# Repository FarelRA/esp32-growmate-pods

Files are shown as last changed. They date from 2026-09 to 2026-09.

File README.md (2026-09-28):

# GrowMate Pods (ESP32-CAM, indoor)

Indoor plant pod: an ESP32-CAM with OV2640 camera monitors a single
plant pot plus its water tank and drives two actuators — a 5 V micro
pump and a full-spectrum LED strip. Six sensing channels (tank level,
light, soil moisture, humidity, temperature, camera) and two command
channels (pump timed in ms, latched grow light). Sense → POST → the
server commands pump / light (never both at once — server-paced
interlock) and serves JPEG stills.

Status: pre-alpha. Device↔server contract is frozen at v1; hardware
is carrier rev A. The matching outdoor unit lives in
`rpi-growmate-tech` (same v1 contract, different iron).

## Features

- Raw-only telemetry (ADC codes + native DHT) with server-side
  calibration; camera JPEG upload on a 15-minute period.
- Timed pump doses (30 s cap, dry-tank interlock) and latched grow
  light (24 h failsafe auto-off), both server-commanded.
- HTTPS OTA with semver gating; MAC-birth identity + server claim flow.
- Full KiCad hierarchy, BOM, and release PDFs in [`schematic/`](schematic/)
  ([pods.pdf](schematic/mfg/pods.pdf)); net-by-net text reference in
  [`docs/04-wiring.md`](docs/04-wiring.md).

## Requirements

- Hardware: AI-Thinker ESP32-CAM module, carrier PCB (see schematic),
  5 V micro pump, 20 cm LED strip, probes, DHT22, BLP673 LiPo pack.
- Host: Python 3 + [PlatformIO](https://platformio.org/) (`pip install
  platformio`), plus a USB-UART adapter for flashing (the module has
  no auto-reset circuit).
- Optional for schematics: KiCad 10 CLI + Inkscape (see
  [`tools/sch_plot.sh`](tools/sch_plot.sh)).

## Installation

```bash
pip install platformio
pio run                    # build .pio/build/growmate-pods/firmware.bin
```

## Usage

Flash (hold BOOT at power-on for download mode, release + reset after):

```bash
pio run --target upload    # uses tools/flash.sh: no_reset/no-stub, 115200
pio device monitor         # or: tools/monitor.sh
```

Onboard: join AP `GrowMate-<last6 of device ID>` with password
`GrowMate-<last6 of WiFi MAC>` from the manufacturing claim sheet
(never the boot log) → `http://192.168.4.1` → home WiFi. Then
calibrate each probe (raw ends stored server-side). Full procedure:
[`docs/07-operations.md`](docs/07-operations.md).

## Tests

```bash
tools/test_all.sh          # Unity suite (PlatformIO native, no hardware)
                           # + host contract checks
```

116 Unity tests, ~98% line coverage of firmware logic
(`pio test -e native` for detail). If the suite and the device ever
disagree, the device wins — then fix the test the same day.

## Docs

`00-overview`, `01-pinout`, `02-power`, `03-sensors-actuators`,
`04-wiring`, `05-firmware`, `06-api`, `07-operations`,
`08-server-changes` — in [`docs/`](docs/). Start at
[`docs/00-overview.md`](docs/00-overview.md); bring-up order lives in
`04-wiring.md`; the server team's contract is `06-api.md` +
`08-server-changes.md`.

## Roadmap

- First field units on rev A carriers (soak + calibration validation).
- Server backend completing the `08-server-changes` contract
  (calibration store, XOR pacing, OTA hosting).
- Rev 2 notes collected in issues: real power-path charger
  (MCP73871 or load-share), probe ESD/TVS.

## Contributing

Private pre-alpha: coordinate before large changes. Rules that keep
the project consistent:

- Tests must stay green (`tools/test_all.sh`); new behavior needs tests.
- Docs change with code — pinout, wiring, power, and API docs are
  normative, not commentary.
- SKiDL (`schematic/pods.py`) is the hardware source of truth; the
  placed sheets follow it via `tools/sch_gate.sh`, never hand edits.

## License

GPLv3 — see LICENSE.

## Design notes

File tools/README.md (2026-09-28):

# Pods tools (run from the repo root)

Device workflow (ESP32-CAM has no auto-reset; never assert DTR/RTS):
- `flash.sh PORT BAUD BUILD_DIR PACKAGES_DIR` — manual flash (also used
  by PlatformIO `upload_command`); factory image goes to ota_0 0x20000.
- `monitor.sh [PORT] [BAUD]` — serial monitor, DTR/RTS forced off.
- `erase.sh PORT [BAUD] [ESPTOOL_PY]` — full chip erase, same discipline.
- `size_report.sh [ENV]` — build size vs `partitions.csv`.

Tests:
- `test_all.sh` — host contract suite + Unity suite (`test/`, once present).

Schematics (flow: SKiDL truth → placed sheets → ERC → compare → plot):
- `sch_gate.sh` — full release gate (fails on any non-waived ERC class).
- `sch_compare.py SKIDL.NET SHEET...` — pin-for-pin netlist compare.
- `sch_plot.sh` — SVG+PNG to `schematic/final/`, merged `schematic/mfg/pods.pdf`.

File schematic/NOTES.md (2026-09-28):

# Pods carrier rev A — release notes (also placed on-sheet)

## Operating rules (binding — defined in docs/, repeated on-sheet)
- Pump/LED XOR, charge idle/low-duty, fuses, GPIO12, probe care:
  `docs/01-pinout.md`, `docs/02-power.md`, `docs/04-wiring.md`. The
  binding instances also sit as on-sheet notes.

## Files
- `pods.py` — SKiDL source of truth (netlist/BOM/ERC). Pin `skidl==2.3.0`.
- `mfg/pods.net` — PCB import. `mfg/pods.xml` — BOM input.
  `mfg/bom.csv` — 41 items.
- `sheets/pods.kicad_sch` + `sheets/pods_s_*.kicad_sch` — hierarchy
  (root + 11 sheets).
- `render.py` + `layout_pods.py` + `pinmap.json` — deterministic
  placement pass (no hand edits in KiCad without back-annotating here).
- `mfg/pods.pdf` — plotted release drawing.

## Release gate (ERC — KiCad 10.0.6 CLI, SKiDL 2.3.0)
0 errors on all 11 sheets. Waived:
1. `isolated_pin_label` — single-ended global labels are the
   inter-sheet ports (e.g. `PUMP_GATE` on `s_mcu`/`s_pump`); mating
   label on the sibling sheet, same nets as `docs/06-api.md`.
2. `lib_symbol_mismatch` on `Diode:1N5819` (pump sheet only) —
   flattened copy of the installed lib's own `1N5819`+`SB120` units;
   connectivity proven independently (zero pin errors, netlist shows
   D1.1 on `PUMP_5V` with M1.1/C11.1, D1.2 on `PUMP_LO` with the rest).
Zero (must stay zero): `pin_not_connected`,
`unconnected_wire_endpoint`, `wire_dangling`, `multiple_net_names`,
`pin_to_pin`, `power_pin_not_driven`, `endpoint_off_grid`,
`no_net_danger`. `footprint_link_issues`/`lib_symbol_issues` appear
only without GUI lib tables (env-only).
Netlist proof: every sheet netlist machine-compared pin-for-pin vs
`mfg/pods.net` — zero mismatches.

## Manual review checklist (signed per release)
- [x] No wire/wire, wire/text, or refdes/symbol overlaps on any sheet
      (visual pass over all 11 PNGs, 2026-09-28).
- [x] Power top, GND bottom, signal left->right on every sheet.
- [x] Every fuse/diode/MOSFET orientation matches 04-wiring (D1 K to
      PUMP_5V branch, F1/F2/F3 feed direction, Q1/Q2 drains to loads —
      confirmed in netlist: D1.2/M1.2/Q1.2 share PUMP_LO).
- [x] `mfg/bom.csv` refs/values/footprints match the placed schematic
      (full netlist compare zero; 12/12 footprints resolve).
- [x] ERC log matches the waiver classes in the Release gate section above.

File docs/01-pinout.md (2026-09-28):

# BEST pin map — ESP32-CAM header-only rotation (rev1)

Verified against: ESP32 datasheet (boot configs), ESP Hardware Design
Guidelines (strapping + ADC tables), AI-Thinker fixed camera/SD/PSRAM map.
No eFuse burn, no SD card, PSRAM kept for the camera. No soldering on
the module itself (header-only, no test-point taps); the carrier's
passives, headers, and SW1 solder as normal.

## Carrier map (U1 = Conn_02x08_Odd_Even, odd = left col, even = right col)

| U1 pin | Net | ESP GPIO | ADC | Why this pin |
|---|---|---|---|---|
| 1 | +5V | 5V rail | — | module supply in |
| 3 | GND | GND | — | |
| 5 | U0RXD | GPIO3 | — | flashing UART RX (edge to adapter TX) |
| 7 | U0TXD | GPIO1 | — | flashing UART TX (edge to adapter RX) |
| 9 | BOOT_IO0 | GPIO0 | ADC2_CH1 | XCLK inside module. 10k PU (R8) = HIGH = SPI boot. Tactile SW1 to GND = flash mode. Nothing else on GPIO0, ever. |
| 11 | +3V3 | 3V3 rail | — | sensor rail out (from module AMS1117) |
| 13, 15 | GND | GND | — | |
| 2 | PUMP_GATE | GPIO2 | ADC2_CH2 | output. Weak pulldown at reset + ext 10k (R3) = MOSFET OFF through the ~3 ms strapping window. GPIO2 strapping wants LOW/float: satisfied. |
| 4 | LIGHT_GATE | GPIO4 | ADC2_CH0 | output. Weak pulldown at reset + ext 10k (R5) = OFF at boot. GPIO4 is **not** a strapping pin (official list: 0, 2, 5, 12/MTDI, 15/MTDO). Shares the onboard flash LED: documented, kept as camera flash. |
| 8 | SOIL_AO | GPIO13 | ADC2_CH4 | input. No strapping, no boot-PWM: the safest analog pin on the header. |
| 10 | LIGHT_AO | GPIO14 | ADC2_CH6 | input. Not a strapping pin. GPIO14 carries the ROM debug PWM probe at boot, so the module AO comes through a 1k series (R6) + 100n to GND (C1): no contention, filtered ADC. |
| 12 | DHT_DATA | GPIO15 | ADC2_CH3 | digital. MTDO needs HIGH at boot: DHT idles HIGH and R1 (4.7k PU) holds it there. DHT is digital so the ADC2/WiFi conflict does not apply. |
| 14 | WATER_AO | GPIO33 | ADC1_CH5 | input. No strapping, no camera bus, and ADC1 reads fine with WiFi on. NOTE: the AI-Thinker red LED hangs on GPIO33 (active-low) — it pulls the high-Z ADC input toward 3V3 against R9 10k PD, shifting EMPTY offset and compressing span (LED may glow dimly); disclosed like the GPIO4 LED, absorbed by server end-calibration, ends must be captured in situ. R9 10k PD to GND so an open (empty-tank) probe reads ~0 instead of floating. |
| 16 | +5V | 5V rail | — | second 5V entry |

## Forbidden / reserved (do not use)

| Pins | Reason |
|---|---|
| 0, 5, 18, 19, 21, 22, 23, 25, 26, 27, 32, 34, 35, 36, 39 | fixed OV2640 bus (`board_profile.c`). Firmware aborts if a sensor/actuator pin overlaps (`sensors_init`, `actuators_init`). |
| 1, 3 | UART0 flash/logs. Reclaim only if you give up serial flashing. |
| 6–11 | internal SPI flash. |
| 16, 17 | PSRAM (camera needs it; GPIO16 use = boot loops). |
| 12 as output / pull-up | MTDI must read LOW or the flash drops to 1.8 V and the board bricks until power-cycle with GPIO12 LOW. |
| SD slot (2, 4, 12, 13, 14, 15 in SD_MMC mode) | firmware never inits SD. All six are carrier GPIO instead. |

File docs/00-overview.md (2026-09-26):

# GrowMate Pods — overview

Indoor pod device. One ESP32-CAM (AI-Thinker, ESP32-S + OV2640) monitors a
single plant pot plus its water tank and drives two actuators. Six sensing
channels, two command channels.

| Direction | Channel | Sensor / actuator |
|---|---|---|
| sense | water level in tank (analog) | resistive probe |
| sense | light (analog) | photodiode module |
| sense | soil moisture (analog) | capacitive v1.2 |
| sense | humidity | DHT22 |
| sense | temperature | DHT22 |
| sense | camera | OV2640, JPEG upload |
| command | water | 5 V micro submersible pump, timed ms |
| command | lighting | full-spectrum LED strip, latched on/off |

Server loop (`POST /api/v1/sensors` → `{commands: [{pump durationMs},
{light enabled}]}`, `POST /api/v1/camera` JPEG) is specified in
[06-api](06-api.md); backend requirements live in
[08-server-changes](08-server-changes.md).

## Documents

| File | Content |
|---|---|
| [01-pinout](01-pinout.md) | BEST header-only pin map, strapping proof, forbidden pins |
| [02-power](02-power.md) | battery, charger, boost, rails, decoupling |
| [03-sensors-actuators](03-sensors-actuators.md) | per-channel circuits and part values |
| [04-wiring](04-wiring.md) | complete net-by-net wiring + parts list (text) and bring-up order |
| [05-firmware](05-firmware.md) | firmware map, ADC-before-WiFi rule, config |
| [06-api](06-api.md) | server contract |
| [07-operations](07-operations.md) | flash, onboard, calibrate, troubleshoot |
| [08-server-changes](08-server-changes.md) | backend requirements: auth, acks, calibration storage, config push, limits |

## Hardware source of truth

- [04-wiring](04-wiring.md) — the complete net list (every net, every
  node), parts list, wire table, bring-up order.
- [01-pinout](01-pinout.md) — pin map with strapping proof.
- `src/board_profile.c` — the pin map in code, plus a camera-bus
  conflict guard that aborts init on overlap (`sensors_init`,
  `actuators_init`). A boot abort here means a wiring bug, not a
  firmware bug.

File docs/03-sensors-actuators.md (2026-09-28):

# Sensors and actuators

Reference designators match the parts list in [04-wiring](04-wiring.md).

## Analog inputs (all 12-bit, 12 dB attenuation, 8-sample average)

| Net | Pin | Module power | Notes |
|---|---|---|---|
| SOIL_AO (J2-2) | GPIO13 ADC2_CH4 | continuous 3V3 | capacitive v1.2, 3V3-safe. Calibrate dry/wet raw. |
| LIGHT_AO (J3-2) | GPIO14 ADC2_CH6 | continuous 3V3 | photodiode module AO → R6 1k → GPIO, C1 100 n to GND. Inverted scale (dark ≈ 4095). |
| WATER_AO (J1-2) | GPIO33 ADC1_CH5 | continuous 3V3 | resistive probe. R9 10k PD to GND (open probe reads ~0 = EMPTY). ADC1 is WiFi-safe. Continuous DC electrolyzes the traces in days–weeks (fertilizer water fastest) — treat it as a consumable: rinse/dry between tanks, recalibrate after moving, stock spares. No spare header pin exists rev1 for switched excitation. Strapping-safe at any water level by construction (GPIO12 unused). |

## Calibration (server-side)

The device reports raw ADC codes and owns no calibration endpoints.
Percent mapping lives on the SERVER, per probe, per install:

| Channel | Server stores | Scale |
|---|---|---|
| water | `EMPTY` (probe in air) vs `FULL` (fully submerged) raw | rising |
| soil | `DRY` (probe in air) vs `WET` (saturated soil) raw | rising |
| light | `DARK` (covered module) vs `BRIGHT` (grow light at canopy) raw | inverted (dark ≈ 4095) |

Procedure (see [07-operations](07-operations.md)): read the raw codes
from a telemetry POST at both ends, store them in the device's
server-side config, then sanity-check a mid-point reading. Moving a
probe or changing its supply invalidates its ends — recalibrate from
scratch. Storage and mapping rules are a server-team contract, detailed
in [08-server-changes](08-server-changes.md).

Firmware sends raw ADC codes only; percent mapping is server-side
(see the calibration section above).

## DHT22 (U2)

VDD 3V3, DATA → GPIO15, GND. Pin 3 is No-Connect per the DHT22
datasheet and stays open — not a wiring omission. Driver is the managed
`esp-idf-lib/dht` component (stateless reads, no ISR service, no
init/deinit dance). R1 4.7k pull-up (also the MTDO-HIGH
strapping pull). 100 nF across VDD/GND at the sensor. Short leads; keep
away from pump wiring. Polled with 2 attempts; failures mark temperature
and humidity unavailable (`NaN`) rather than blocking the cycle.

## Pump (M1) and grow light (D2) — low-side N-MOSFETs

| | Pump | Light |
|---|---|---|
| GPIO | GPIO2 → R2 220R → gate node | GPIO4 → R4 220R → gate node |
| Pulldown | R3 10k gate–GND | R5 10k gate–GND |
| FET | Q1 IRLZ44N (logic-level, Vgs(th) < 2 V), source GND, drain PUMP_LO | Q2 same, drain LED_LO |
| Load | M1 between PUMP_5V and PUMP_LO | LED strip between LED_5V and LED_LO |
| Protection | D1 1N5822 flyback, cathode PUMP_5V, anode PUMP_LO | strip modules are LED+resistor; no flyback needed |

Behavior (`src/actuators.c`): pump command `{durationMs}` turns the FET on
and auto-offs via an authoritative `esp_timer` one-shot (plus a 250 ms
`actuators_tick` backup in `delay_with_housekeeping`); the contract caps
doses at 30 s (`0 < durationMs <= 30000`, water channel must read — see
[06-api](06-api.md)). Light command latches on/off with a 24 h failsafe
auto-off refreshed by re-sent "on". Both report back
in `currentState`, and command ids are echoed in `acceptedCommandIds`.

GPIO4 also drives the onboard flash LED (voltage-divider fed, glows dimly
even "off"). Kept deliberately: the camera flash still works. If the glow
bothers a dark grow cycle, remove R11 on the module (see AI-Thinker
schematic) — do not rewire GPIO4.

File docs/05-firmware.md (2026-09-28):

# Firmware map

ESP-IDF 5.5, PlatformIO, C17. Entry `app_main` in `src/main.c`.

## Cycle (every effective report interval, default 15 s)

```
sensors_read_all()          # ADC burst + DHT, WiFi still STOPPED
network_manager_start_station()   # connect, 12 s timeout
upload_sensor_snapshot()    # POST sensors, 2 tries, apply commands + config + claim
upload_camera_image()       # if due (build-time 900 s)
ota_service_run_if_needed() # upgrade + restart when server offers newer build
network_manager_stop()      # WiFi fully stopped again
delay_with_housekeeping()   # 250 ms ticks service the pump timer
```

The sensor interval is the server-pushed `reportIntervalSec`
(10–3600 s, persisted in NVS v1, echoed as `appliedConfigRev`) when
one has been received, else the build default
`APP_SENSOR_INTERVAL_SEC` (15 s). The camera period stays build-time
(`APP_CAMERA_INTERVAL_SEC`, 900 s) and is not server-configurable.

**ADC-before-WiFi is load-bearing.** ADC2 (GPIO13/14) is shared with
the WiFi driver on ESP32 classic: any ADC2 read between `esp_wifi_start`
and `esp_wifi_stop` fails. Water lives on ADC1 (GPIO33, WiFi-safe) but
soil/light keep the rule, so the order above is the entire workaround.
Do not "optimize" it into a persistent connection without moving to an
external ADC.

Camera init/deinit brackets each capture (PSRAM: SVGA/Q12, else VGA/Q14).
`loops_since_camera` starts at one full period so the first boot captures
immediately (intended: instant visual check after install).

5 consecutive failures (WiFi, upload, camera, or total sensor
failure) reopen the onboarding AP portal instead of wedging.

## Files

| File | Owns |
|---|---|
| `board_profile.{h,c}` | THE pin map (must match 01-pinout). Camera bus + conflict check. |
| `sensors.{h,c}` | 8-sample ADC average (ADC2 soil/light, ADC1 water), raw-only capture, DHT poll, continuous-3V3 water probe, camera-bus abort guard. |
| `actuators.{h,c}` | GPIO2/4 init (no internal pull — external network owns boot level), one-shot timed pump (30 s contract cap), latched light with 24 h failsafe auto-off, conflict abort guard. |
| `api_client.{h,c}` | sensor JSON POST (raw envelope + `health` + `acceptedCommandIds`, Bearer token when configured) with command/config parse (`pump durationMs` ≤ 30 s with water check, `light` bool-or-number), JPEG POST with `X-Device-Id` + token. |
| `app_config.{h,c}` | NVS `growmate/settings` v1: WiFi SSID/pass + provisioned flag + assigned device ID + boot count + applied config rev + report interval. Any size/version mismatch resets to defaults (pre-alpha: no migration, re-provision + reclaim). |
| `device_identity.{h,c}` | MAC birth ID, effective ID, derived onboarding AP credentials. |
| `ota_service.{h,c}` | semver compare + HTTPS OTA + restart. |
| `network_manager.{h,c}` | STA connect/scan + onboarding AP + stop. |
| `onboarding.{h,c}` | blocking portal at 192.168.4.1: `GET /`, `GET /api/config`, `POST /api/config{wifiSsid,wifiPassword}`, `GET /api/networks`. AP name `GrowMate-<last6 of device ID>`, WPA2 password `GrowMate-<last6 of MAC>` from the manufacturing claim sheet (never the log). Plaintext HTTP — commission in a trusted location (see 07-operations). |
| `camera_service.{h,c}` | PWDN pulse, init/deinit, capture. |
| `api_rules.{h,c}` | pure validators (ids, dose window, rev discipline, clamps, charsets). |
| `api_parse.{h,c}` | cJSON traversal for commands/config/claim/OTA + id ring. |
| `ota_logic.{h,c}` | semver parse/compare + upgrade gate. |
| `onboarding_rules.{h,c}` / `network_rules.{h,c}` | portal field copy, AP/station/scan guards. |
| `camera_logic.{h,c}` / `main_logic.{h,c}` | frame pick, interval scheduling. |
| `app_build_config.h` | device ID, firmware version, API URLs, token, sensor/camera intervals. Per-device values: edit + reflash. |

Unity tests live in `test/` (PlatformIO native env, no hardware);
`tools/test_all.sh` runs them. See `tools/README.md`.

## Configuration tiers

- **Build time** (`app_build_config.h`): identity, token, URLs,
  intervals — reflash to change.
- **Runtime**: WiFi credentials via portal (NVS); assigned device ID via
  server claim (NVS v1, effective immediately); report interval +
  config rev via server push (NVS v1, echoed as `appliedConfigRev`).
  Calibration lives server-side ([03-sensors-actuators](03-sensors-actuators.md)).

## Known firmware limits

- Auth: `Authorization: Bearer` is sent when a token is compiled in;
  until then the server must allowlist device IDs (`deviceId` in the
  JSON body and `X-Device-Id` on camera POSTs are identifiers, not
  credentials).
- Status handling: 2xx ok; 429 honors `Retry-After`; other 4xx are
  fatal-for-request (no retry, NO portal reopen); 5xx/transport errors
  retry with backoff.
- `deviceId`/`firmwareVersion` are compile-time defaults; the server
  assigns the pod ID via the claim flow (`claim: {deviceId}`, persisted
  NVS v1, effective immediately). Birth identity is always the WiFi MAC
  (`hardwareId`).
- OTA is live: dual 1.5 MB slots, server offers `minFirmware` +
  `firmwareUrl`, device upgrades when newer (never mid pump-dose) and
  restarts. No rollback slot — keep the previous binary to re-offer.
  A latched light goes dark across the reboot; the server refreshes it.
- Remote diagnosis beyond the `health` block is serial-only
  (`pio device monitor`, 115200).
- Portal `httpd` worker task runs with an 8 KB stack (set in code at
  server start; the handlers hold multi-KB buffers).
- Watchdog: `app_main` is subscribed to the task watchdog (60 s window).
  Every blocking path (WiFi join, HTTP POSTs, OTA download, portal,
  sensor sampling, interval wait) feeds it at least once per second, so
  a trip means a genuine wedge, not a slow network.
- No deep sleep: ~60 mA idle on USB/pack. Battery runtime ≈ pack/average
  draw; size accordingly.

## Dependencies

- `src/idf_component.yml` declares `esp-idf-lib/dht ^1.2.0` (DHT22 reads —
  stateless, no ISR service) and `espressif/esp32-camera ^2.1.8`. The
  component manager downloads them (plus `esp_idf_lib_helpers` and
  `esp_jpeg`) into `managed_components/` on every build. There is no
  `components/` dir anymore.
  NOTE: under PlatformIO only the **main-component manifest** (`src/`) is
  honored — a project-root `idf_component.yml` is silently ignored, so deps
  must stay declared in `src/`.
- The old vendored `esp32-camera` carried a local `ll_cam.c` patch (fail
  fast on GPIO-ISR-service install errors other than ALREADY_INSTALLED).
  Upstream 2.1.8 ignores the return value instead — behaviorally identical
  in the working path (deinit removes the handler but keeps the shared
  service, so re-init hits ALREADY_INSTALLED and proceeds). Patch dropped
  as not load-bearing; nothing else installs the ISR service anymore since
  the DHT driver went stateless.
- `esp_jpeg` is pulled transitively by `esp32-camera`'s manifest but never
  called directly — harmless payload, kept (removing it means forking the
  camera manifest).

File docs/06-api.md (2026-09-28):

# Server contract (Pods)

Two endpoints, canonical versioned paths. Base URL, firmware
version, and token are build-time constants (`src/app_build_config.h`);
`deviceId` is the effective identity (server-claimed pod ID persisted in
NVS, else the build default) plus the immutable MAC `hardwareId`.

| Channel | Method + path | Body |
|---|---|---|
| sensors | `POST /api/v1/sensors` | `application/json` envelope, every report interval (default 15 s) |
| camera | `POST /api/v1/camera` | `image/jpeg` raw frame when due (default 900 s) |

## Auth

`Authorization: Bearer <token>` on both endpoints when a token is
configured at build time. Camera POSTs additionally carry
`X-Device-Id: <deviceId>`. A `401` means unknown, expired, or missing
token: do not retry the request; keep sensing and surface the device
for re-provisioning.

## POST sensors — request envelope

```json
{
  "deviceId": "IAET01",
  "hardwareId": "7C87CE1A2B3C",
  "firmwareVersion": "2.0.0",
  "snapshotId": "B12-345",
  "ageMs": 1800,
  "appliedConfigRev": 7,
  "sensors": [
    {"kind": "soil", "unit": "%", "raw": 2048},
    {"kind": "light", "unit": "%", "raw": 3200},
    {"kind": "water", "unit": "%", "raw": 3800},
    {"kind": "temperature", "unit": "C", "value": 24.6},
    {"kind": "air", "unit": "%", "value": 61.2}
  ],
  "acceptedCommandIds": ["cmd-9f2"],
  "currentState": {"pumpEnabled": false, "lightEnabled": true},
  "health": {"heapFree": 81234, "rssi": -61, "uptimeS": 86412,
             "bootCount": 12, "resetReason": "power-on",
             "dhtFails": 1, "adcFails": 0}
}
```

| Field | Type | Bounds / notes |
|---|---|---|
| `deviceId` | string | effective identity: server-assigned pod ID after claiming, else build default; also the allowlist key |
| `hardwareId` | string | birth identity: uppercase WiFi-MAC hex, always sent, never changes; claim/review key for unclaimed units |
| `firmwareVersion` | string | semver, e.g. `"2.0.0"` |
| `snapshotId` | string | `"B<bootCount>-<seq>"`, unique per sample; server dedup key |
| `ageMs` | int | `>= 0`, sampling-to-POST latency (includes WiFi join, up to ~12 s, by design); server reconstructs sample time as `receivedAt - ageMs` |
| `appliedConfigRev` | int | `>= 0`, last config rev applied (0 = none) |
| `sensors[]` | array | raw-only analog + native DHT entries (kinds below); unavailable sensors omitted, never null |
| `acceptedCommandIds[]` | string[] | ids of commands applied since the previous POST (empty is valid) |
| `currentState` | object | `{pumpEnabled: bool, lightEnabled: bool}` latch state at POST time |
| `health` | object | `{heapFree: bytes int, rssi: dBm int, uptimeS: int, bootCount: int, resetReason: string, dhtFails: int, adcFails: int}` cumulative counters |

Sensor kinds:

| kind | Shape | Notes |
|---|---|---|
| `soil`, `light`, `water` | `{kind, unit: "%", raw: 0–4095}` | RAW-ONLY. No percent math on device; server maps raw→percent via stored per-probe ends. Light scale inverted (dark ≈ 4095). |
| `temperature` | `{kind, unit: "C", value: float}` | native DHT22 °C, no `raw` |
| `air` | `{kind, unit: "%", value: float}` | native DHT22 %RH, no `raw` |

## POST sensors — response

```json
{"commands": [{"kind": "pump", "durationMs": 5000, "id": "cmd-9f3"}],
 "config": {"rev": 8, "reportIntervalSec": 30}}
```

Pump XOR light is SERVER-PACED: never send both in one response
(combined 3.8 A run / 4.8 A stall leaves no margin on the 4 A boost —
stall exceeds it, the rail browns out and the pod reboot-loops). The
device applies whatever it receives.

Both keys optional; either may be absent. Unknown command `kind`
values are ignored.

### Command validation (device rule)

| Command | Accepted iff | Effect |
|---|---|---|
| `{kind: "pump", durationMs, id}` | `0 < durationMs <= 30000` (finite) AND water channel readable AND non-empty `id` (< 32 chars) | pump FET on for `durationMs` (one-shot, 30 s cap); `id` echoed in `acceptedCommandIds` |
| `{kind: "light", enabled, id}` | `enabled` is bool or finite number (0 = off, nonzero = on) AND non-empty `id` (< 32 chars) | latch grow light; `id` echoed in `acceptedCommandIds` |

`id` is a server-generated string echoed verbatim and is REQUIRED.
Id-less or overlong-id commands are ignored (an applied-but-unackable
command would leave server and device permanently disagreed).

### Config push

`config.rev` is an int, strictly increasing. `config.reportIntervalSec`
is 10–3600 s. The device persists rev + interval (NVS v1), applies the
interval to the sensor cycle, and echoes `appliedConfigRev` on the next
POST. Stale revs (`rev <= appliedConfigRev`) are ignored;
out-of-range intervals are clamped to 10–3600 s (rev still advances).
The camera period stays build-time (900 s).

## POST camera — when due, `Content-Type: image/jpeg`

Headers `Authorization` (when configured) + `X-Device-Id: <deviceId>`,
body = raw JPEG (typically 20–100 KB, 45 s timeout). Any 2xx = success;
a failed frame retries at the next due slot.

## Status codes

| Status | Device behavior |
|---|---|
| 2xx | ok; apply commands + config |
| 429 | wait `Retry-After` (cap 60 s), then skip to next cycle; never retried in-cycle, never counted |
| other 4xx (incl. 401) | fatal for the request: no retry, NO portal reopen; keep sensing, surface for operator |
| 5xx / transport error | retryable with backoff; counts toward the failure threshold |

## Retry / ack / dedup / time correction

- Telemetry is at-least-once: the server dedups on `snapshotId`
  (`B<boot>-<seq>`, one id per sample, never reused).
- Commands are at-least-once the other way: the server re-delivers any
  command whose `id` is absent from `acceptedCommandIds` until it is
  acked or superseded. Command handling is idempotent on both sides.
- The device has no RTC: `ageMs` is the only sample-timing truth.
  Server timestamp = `receivedAt - ageMs`; never use arrival time raw.
- `currentState` + `acceptedCommandIds` together let the server
  distinguish "command lost" from "command applied, ack lost".

## Claim + OTA (live)

- Claim: answer any sensor POST with `claim: {deviceId: "<pod-id>"}`
  (`[A-Za-z0-9_-]`, ≤31 chars). The device validates, persists (NVS),
  and reports the new `deviceId` from the next POST; the onboarding AP
  name follows it. Repeat sends are no-ops. See `08-server-changes` §10.
- OTA: offer with `minFirmware: "x.y.z"` + `firmwareUrl: "https://…"`.
  The device upgrades only when the offer is newer than its own build,
  never mid pump-dose, then restarts into the new image (dual OTA slots,
  1.5 MB each — images must fit). No rollback slot: keep the previous
  binary to re-offer on regression. A latched grow light goes dark
  across the reboot; the server should refresh the latch afterwards.

## Test against a stub

```bash
curl -X POST "$SENSOR_URL" -H 'Content-Type: application/json' \
  -H 'Authorization: Bearer TEST-TOKEN' -d \
  '{"deviceId":"TEST01","hardwareId":"7C87CE1A2B3C","firmwareVersion":"2.0.0","snapshotId":"B1-1", \
    "ageMs":100,"appliedConfigRev":0, \
    "sensors":[{"kind":"soil","unit":"%","raw":2048}], \
    "acceptedCommandIds":[], \
    "currentState":{"pumpEnabled":false,"lightEnabled":false}, \
    "health":{"heapFree":80000,"rssi":-60,"uptimeS":10,"bootCount":1, \
              "resetReason":"power-on","dhtFails":0,"adcFails":0}}'
curl -X POST "$CAM_URL" -H 'Content-Type: image/jpeg' \
  -H 'X-Device-Id: TEST01' -H 'Authorization: Bearer TEST-TOKEN' \
  --data-binary @test.jpg
```

## Implementation notes (verified in `src/`, current firmware)

- Posts to the compiled `/api/v1/sensors` and `/api/v1/camera`
  (`APP_SENSOR_API_URL`, `APP_CAMERA_API_URL`); `Authorization` sent only
  when a token is compiled in, otherwise allowlist on `deviceId`.
- Analog entries carry `raw` only (no device percent math, no endpoints
  in firmware); DHT entries carry native floats. Unavailable omitted.
- Envelope carries `deviceId` (+`hardwareId`), `snapshotId`, `ageMs`,
  `appliedConfigRev`, `acceptedCommandIds`, `health` (NVS v1).
  Report interval is server-pushed (rev discipline); camera stays 900 s.
- Pump needs `0 < durationMs <= 30000` plus a readable water channel and
  a non-empty `id`; light takes bool or finite number plus `id`;
  accepted ids echo next POST.
- 2xx ok; 429 waited out then skipped to next cycle (no count);
  other 4xx fatal-no-count; 5xx/transport counted.
  Retries: 2 tries 1.5 s apart per cycle; fatal/429 break after the first try.
- OTA + claim as above; light auto-offs after 24 h without a refresh.

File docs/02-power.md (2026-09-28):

# Power chain

```
USB-C 5V ──┬──► XL6009 boost ──► +5V rail ──► ESP 5V, M1 pump, D2 LED strip
           │
BLP673 3.85V 4230mAh ──► TP4056 (Type-C, DW01A) ── charge path ──► pack
           │
           └── system always runs from the pack via boost (UPS style)
```

- Charge: TP4056 to 4.2 V. WARNING: with system load on the pack
  during charge, termination taper never completes — the cell floats
  at 4.20 V indefinitely (DW01A 4.30 V backs it up, but the pouch ages
  fast). Operating rule rev1: charge with the pod idle/low-duty, and
  verify the load hangs on OUT± (never B±, or DW01A discharge
  protection is bypassed too). Rev2: real power-path (MCP73871 or
  P-FET load-share).
- Boost: XL6009 5 V / 4 A from pack voltage (3.0–4.2 V), heatsink
  fitted for 3 A+ sustained (LED 24 h failsafe).
  Budget (measured loads): ESP peak ~800 mA (WiFi + camera) + pump
  1 A run / 2 A stall + LED strip 20 cm 2 A. Pump and LED are NEVER
  on together (server-paced interlock — combined 3.8 A run / 4.8 A
  stall browns out any single boost; the firmware obeys whatever the
  server sends, so the API example shows pump alone).
  Interlocked worst case (ESP + LED) is 2.8 A @ 5 V ≈ 5.3 A in at a
  3.0 V pack (sustained worst 2.3 A out ≈ 4.4 A in — inside F1 5 A hold;
  30 s pump stall transient rides the slow PTC): F1 is 5 A hold (2920)
  and the pack→boost run is 1.5 mm².
- Rails: sensors from module 3V3 **only** (AMS1117). Never 5 V into a GPIO
  or a 3V3 sensor header. Pump and LED strip on +5V only.
- Decoupling: C2 1000 µ bulk + C3 100 n ceramic at the module 5V entry;
  100 n at the DHT VCC; C1 100 n doubles as the light-AO filter.
  Add: 10 µF at +3V3 (U1-11), 100 nF at each probe header VCC/GND,
  1 kΩ + 100 nF footprints at soil (U1-8) and water (U1-14) inputs,
  100 nF across the pump terminals, 330 Ω in series with the tank-probe
  VCC feed (dead-short → 10 mA, not a rail collapse).
- Brownout rule: short, thick USB cable or charged pack before flashing;
  random reboots / camera-init failures / WiFi drops = power first suspect.
- Test points: +5V at U1-1/16, +3V3 at U1-11, GND at U1-3/13/15.

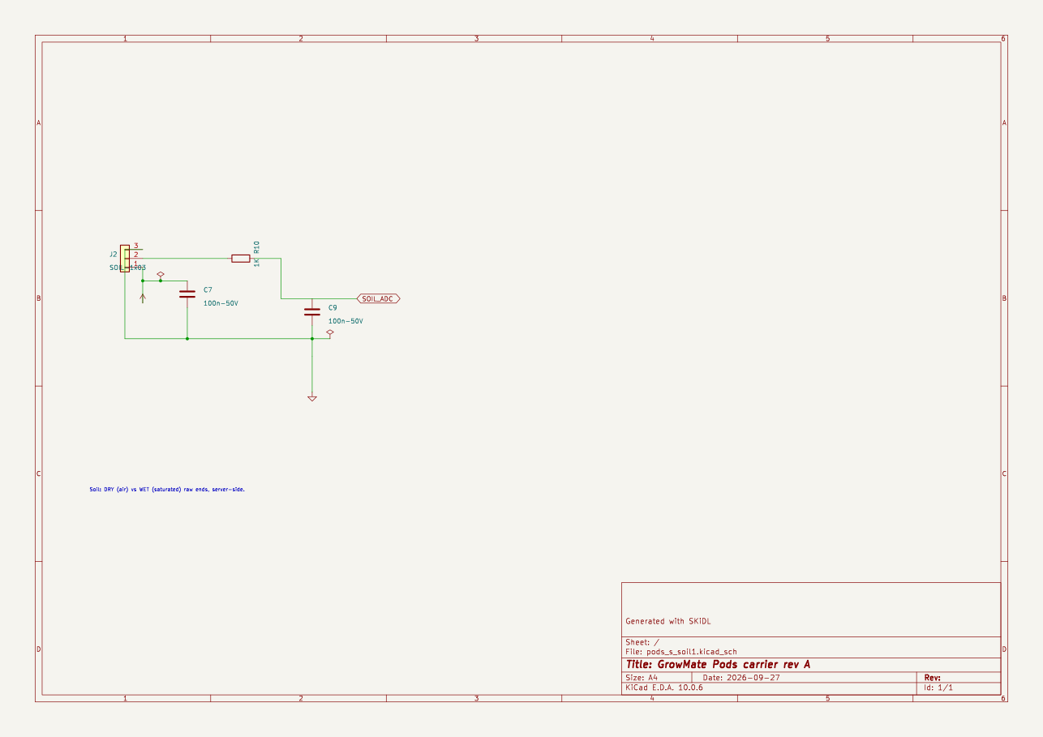
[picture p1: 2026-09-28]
schematic/final/pods-s_soil1.png

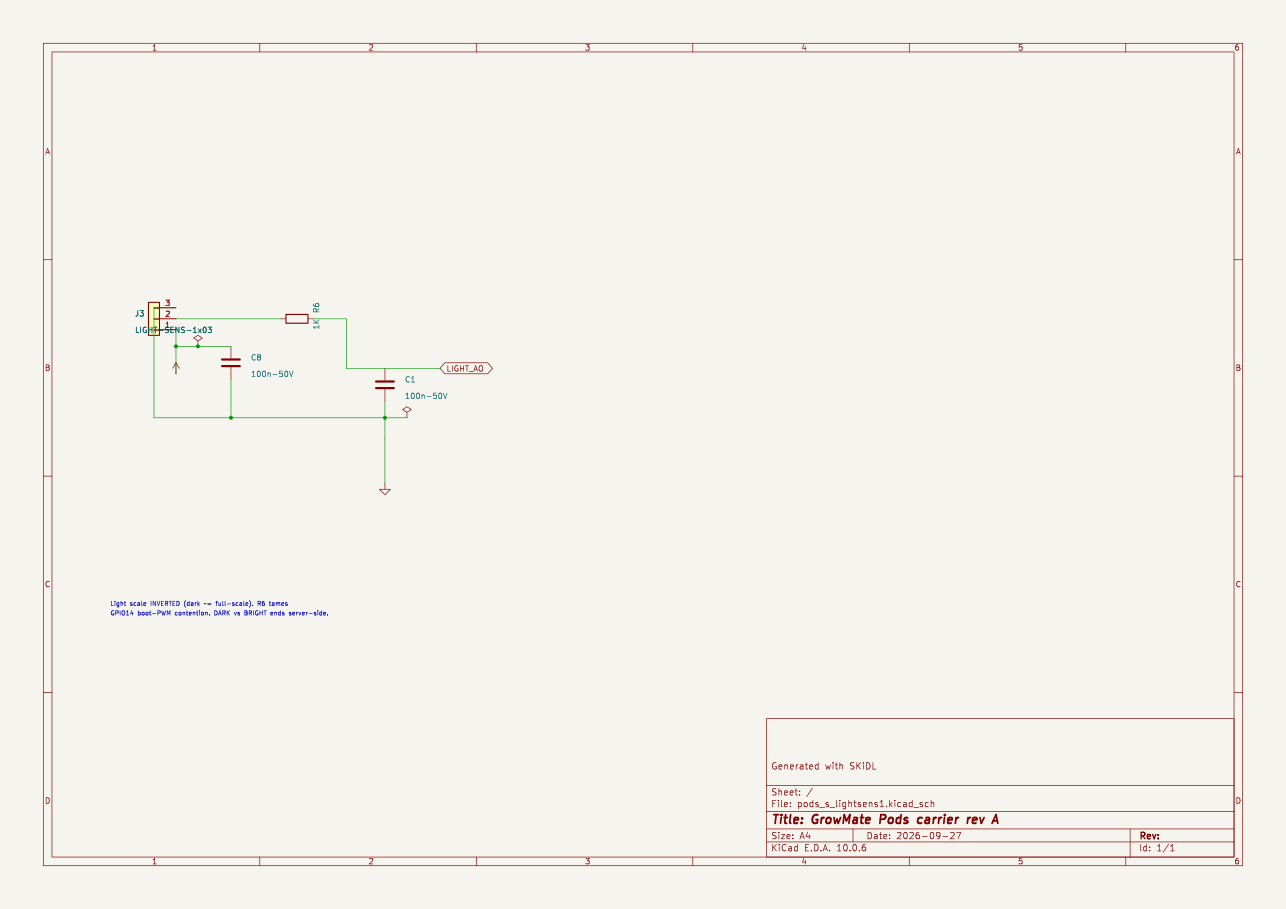
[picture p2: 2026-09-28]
schematic/final/pods-s_lightsens1.png

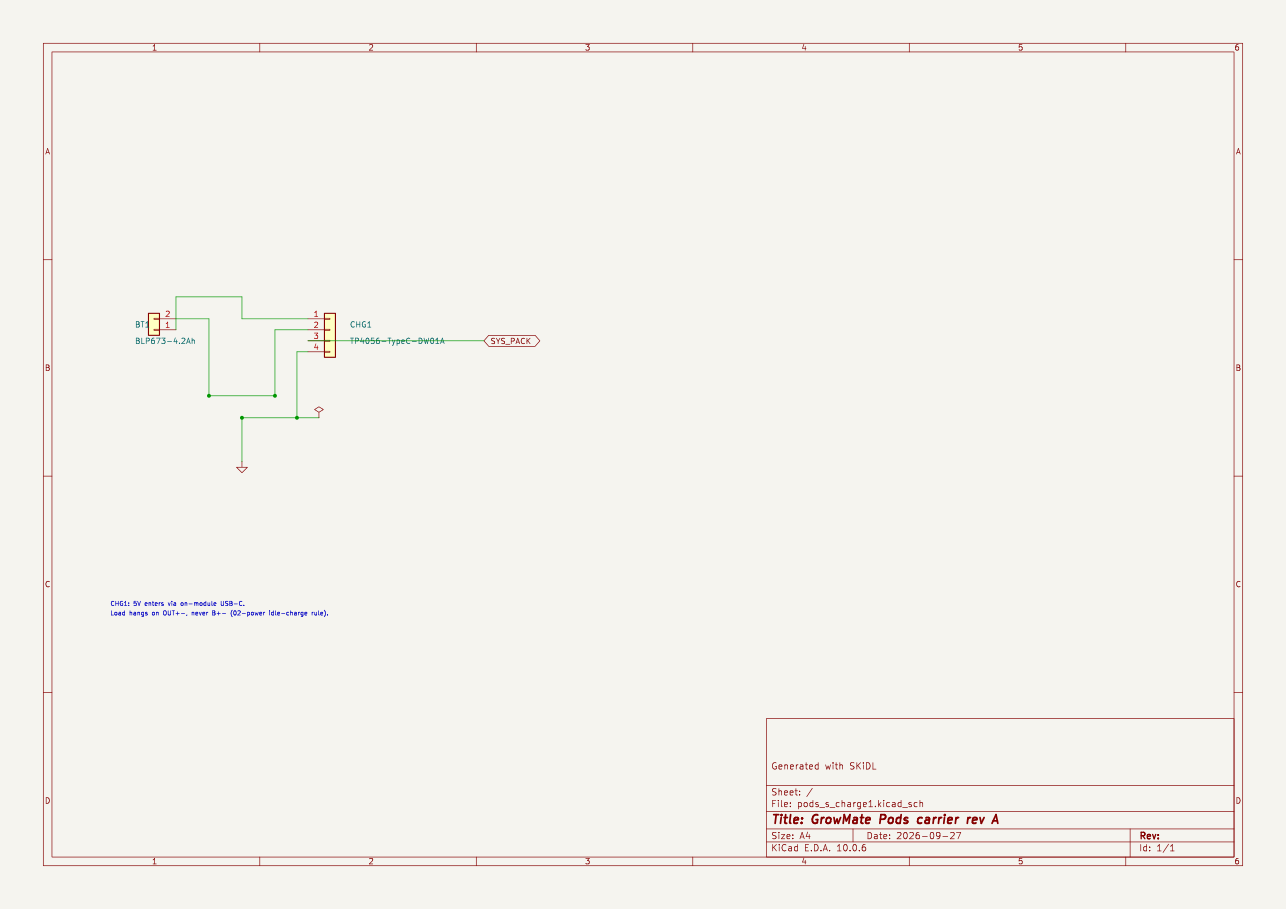
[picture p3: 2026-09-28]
schematic/final/pods-s_charge1.png

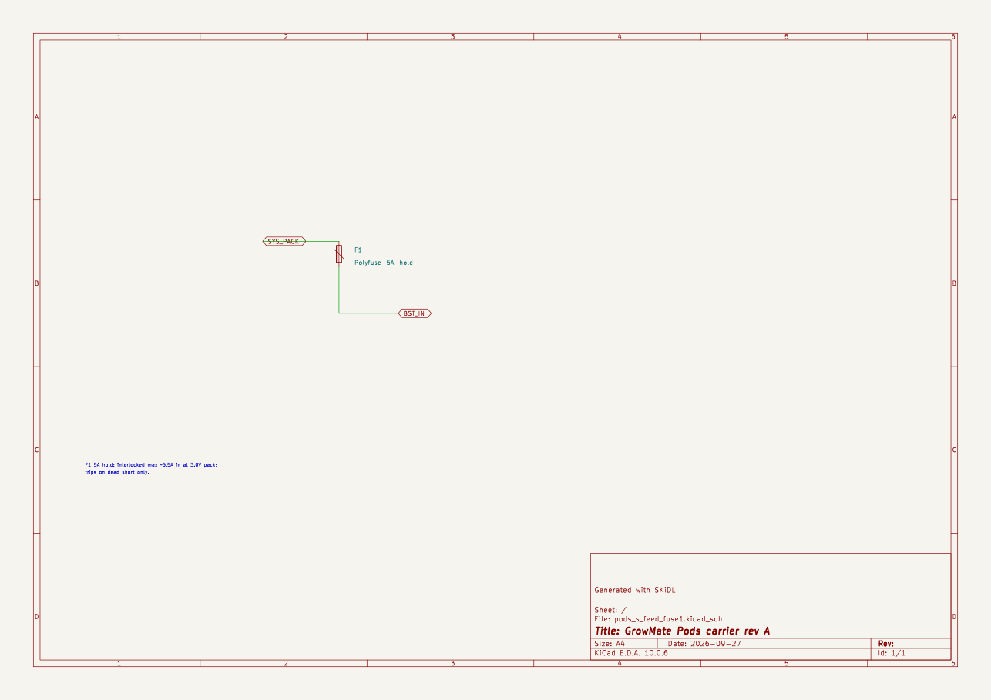
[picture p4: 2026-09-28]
schematic/final/pods-s_feed_fuse1.png

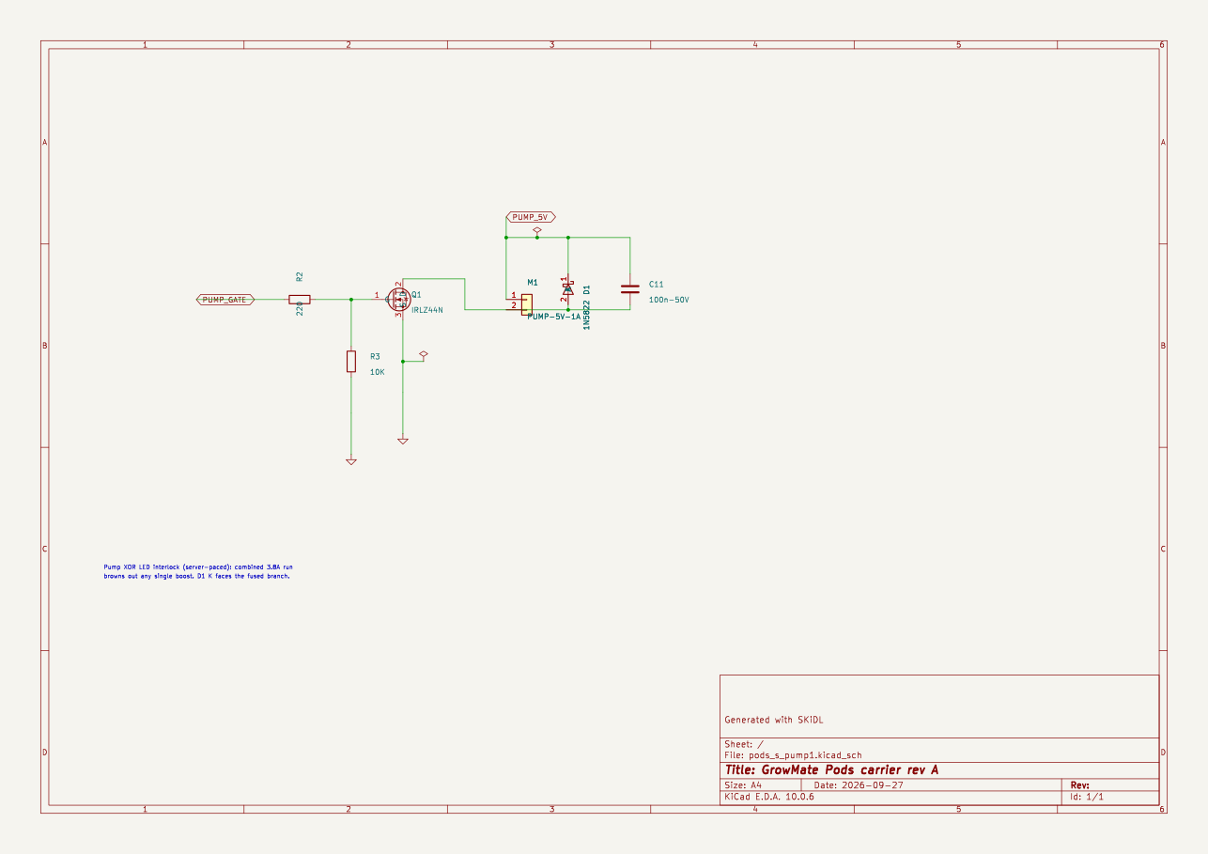
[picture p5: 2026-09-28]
schematic/final/pods-s_pump1.png

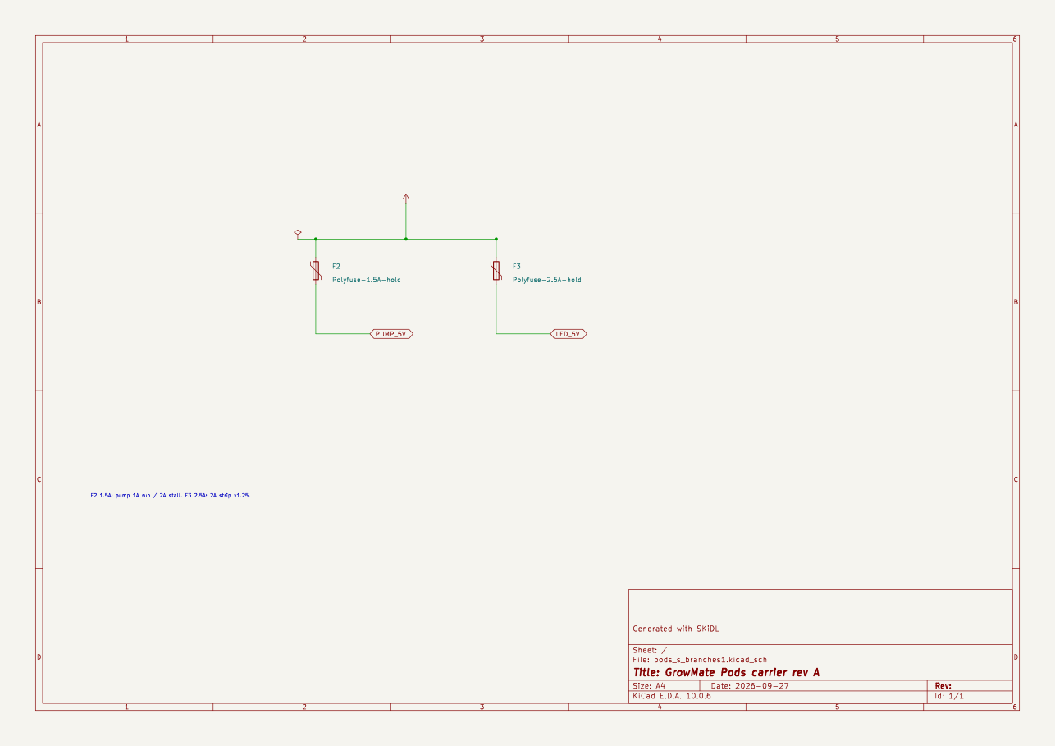
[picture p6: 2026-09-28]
schematic/final/pods-s_branches1.png

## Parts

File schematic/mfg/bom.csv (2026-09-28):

ref | value | footprint | function
BST1 | XL6009-5V-4A | Connector_PinHeader_2.54mm:PinHeader_1x04_P2.54mm_Vertical | boost module 4 A (3.0-4.2 V in; heatsink on for 3 A+ sustained)
BT1 | BLP673-4.2Ah | Connector_PinHeader_2.54mm:PinHeader_1x02_P2.54mm_Vertical | LiPo pouch BLP673 3.85 V 4230 mAh (cell return = CELL_NEG)
C1 | 100n-50V | Capacitor_SMD:C_0603_1608Metric | light-AO filter
C10 | 100n-50V | Capacitor_SMD:C_0603_1608Metric | water input filter
C11 | 100n-50V | Capacitor_SMD:C_0603_1608Metric | pump terminal RF shunt
C2 | 1000u-10V | Capacitor_THT:CP_Radial_D8.0mm_P3.50mm | 5 V bulk at module entry
C3 | 100n-50V | Capacitor_SMD:C_0603_1608Metric | 5 V ceramic at module entry
C4 | 100n-50V | Capacitor_SMD:C_0603_1608Metric | DHT VCC decoupling at U2
C5 | 10u-6V3 | Capacitor_SMD:C_0603_1608Metric | +3V3 bulk at U1-11
C6 | 100n-50V | Capacitor_SMD:C_0603_1608Metric | tank header decoupling
C7 | 100n-50V | Capacitor_SMD:C_0603_1608Metric | soil header decoupling
C8 | 100n-50V | Capacitor_SMD:C_0603_1608Metric | light header decoupling
C9 | 100n-50V | Capacitor_SMD:C_0603_1608Metric | soil input filter
CHG1 | TP4056-TypeC-DW01A | Connector_PinHeader_2.54mm:PinHeader_1x04_P2.54mm_Vertical | charger module (5 V in via on-board USB-C; load on OUT)
D1 | 1N5822 | Diode_THT:D_DO-41_SOD81_P7.62mm_Horizontal | pump flyback 3A class (K to PUMP_5V branch)
D2 | GROW-LED-5V-20CM-2A | Connector_PinHeader_2.54mm:PinHeader_1x02_P2.54mm_Vertical | full-spectrum strip (A to fused +5V, K to LED_LO)
F1 | Polyfuse-5A-hold | Fuse:Fuse_2920_7451Metric | pack overcurrent (interlocked max ~5.5 A in at 3.0 V)
F2 | Polyfuse-1.5A-hold | Fuse:Fuse_1812_4532Metric | pump branch (1 A run / 2 A stall)
F3 | Polyfuse-2.5A-hold | Fuse:Fuse_1812_4532Metric | LED branch (2 A strip, 1.25x rule)
J1 | WATER-1x03 | Connector_PinHeader_2.54mm:PinHeader_1x03_P2.54mm_Vertical | tank probe (VCC/AO/GND)
J2 | SOIL-1x03 | Connector_PinHeader_2.54mm:PinHeader_1x03_P2.54mm_Vertical | soil probe (3V3/AO/GND)
J3 | LIGHT-SENS-1x03 | Connector_PinHeader_2.54mm:PinHeader_1x03_P2.54mm_Vertical | light module (3V3/AO/GND)
J4 | PROG-1x04 | Connector_PinHeader_2.54mm:PinHeader_1x04_P2.54mm_Vertical | flash header (adapter TX->J4-1, RX<-J4-2)
M1 | PUMP-5V-1A | Connector_PinHeader_2.54mm:PinHeader_1x02_P2.54mm_Vertical | micro pump (1 A run / 2 A stall, off-board)
Q1 | IRLZ44N | Package_TO_SOT_THT:TO-220-3_Vertical | pump low-side N-MOSFET (logic-level)
Q2 | IRLZ44N | Package_TO_SOT_THT:TO-220-3_Vertical | light low-side N-MOSFET (logic-level)
R1 | 4.7K | Resistor_SMD:R_0603_1608Metric | DHT pull-up (MTDO-HIGH strapping)
R10 | 1K | Resistor_SMD:R_0603_1608Metric | soil input series
R11 | 1K | Resistor_SMD:R_0603_1608Metric | water input series
R2 | 220 | Resistor_SMD:R_0603_1608Metric | pump gate stopper
R3 | 10K | Resistor_SMD:R_0603_1608Metric | pump gate pulldown (OFF at boot)
R4 | 220 | Resistor_SMD:R_0603_1608Metric | light gate stopper
R5 | 10K | Resistor_SMD:R_0603_1608Metric | light gate pulldown (OFF at boot)
R6 | 1K | Resistor_SMD:R_0603_1608Metric | light series (boot-PWM contention)
R7 | 330 | Resistor_SMD:R_0603_1608Metric | tank VCC series (dead-short -> 10 mA)
R8 | 10K | Resistor_SMD:R_0603_1608Metric | BOOT pull-up (SPI boot HIGH)
R9 | 10K | Resistor_SMD:R_0603_1608Metric | water pulldown (open probe ~0 = EMPTY)
SW1 | BOOT-TACT | Button_Switch_THT:SW_PUSH-12mm | IO0 to GND for download mode
U1A | ESP32-CAM-ODD | Connector_PinHeader_2.54mm:PinHeader_1x08_P2.54mm_Vertical | AI-Thinker module, odd row (U1-1..15)
U1B | ESP32-CAM-EVEN | Connector_PinHeader_2.54mm:PinHeader_1x08_P2.54mm_Vertical | AI-Thinker module, even row (U1-2..16)
U2 | DHT22 | Connector_PinHeader_2.54mm:PinHeader_1x04_P2.54mm_Vertical | temp+humidity (DHT11 symbol, DHT22 pin-compatible)

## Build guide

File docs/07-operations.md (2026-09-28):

# Operations: flash, onboard, calibrate, troubleshoot

## Flash

Wiring (USB-serial adapter, 5V-tolerant I/O at 3V3):

```
adapter GND → ESP GND | adapter 5V → ESP 5V
adapter TX  → ESP U0R | adapter RX  → ESP U0T
IO0 → GND (only while powering on for download mode)
```

```bash
pip install platformio
pio run                    # build .pio/build/growmate-pods/firmware.bin
pio run --target upload    # tools/flash.sh: esptool, no_reset/no-stub, 115200
pio device monitor           # 115200, RTS/DTR held (see monitor_* in ini)
```

Remove the IO0–GND link and reset to boot normally. If the port is not
autodetected, override with
`pio run --target upload --upload-port /dev/ttyUSB0` as needed.
Single 5V source while flashing: the adapter powers the module, so
disconnect the pack/boost 5V feed first — never drive the +5V rail from
two supplies at once.
First provisioned boot captures a camera frame immediately (a fresh
device blocks in the portal first) — use it as the install photo check.

## Onboard

1. Join AP `GrowMate-<last6 of device ID>` (default `GrowMate-IAET01`).
   Password is per-device: `GrowMate-<last6 of WiFi MAC>` from the
   manufacturing claim sheet (never the boot log — the firmware
   deliberately does not print it). (No more shared password.)
2. Open `http://192.168.4.1`, submit home WiFi SSID/pass.
3. Device continues with the new settings (no reboot) into station mode
   and starts the 15 s cycle.
4. After 5 straight failures the portal reopens by itself (transport
   and 5xx errors; 4xx responses are fatal-for-request and never force
   the portal — see [06-api](06-api.md)).

Portal notes: the AP password is per-device (derived from the MAC, see
above) but the portal itself is plaintext HTTP — anyone in range can
sniff the home WiFi credentials you type. Commission in a trusted
location. Remote diagnosis beyond the `health` block
in telemetry is serial-only (`pio device monitor`, 115200).

## Calibrate (per probe, per install — server-side)

For each analog channel, read the raw codes from a telemetry POST at
both ends and store them in the device's SERVER-side config (mapping
rules in [08-server-changes](08-server-changes.md)):

- water: probe in air (EMPTY) vs fully submerged (FULL). No defaults
  are shipped — calibrate every install from scratch.
- soil: probe in air (DRY) vs in saturated soil (WET).
- light: covered module (DARK) vs grow light at canopy (BRIGHT).
  Scale is inverted (dark ≈ 4095).

The device holds no calibration endpoints — `raw` is authoritative and
the server owns the mapping. Moving a probe invalidates its stored ends.

## Soak test (before install)

Run the pod on pack power for at least one full camera period plus
several sensor cycles, with WiFi connected: camera init + capture +
JPEG upload is the peak-draw event (ESP + camera + WiFi, plus pump/LED
if commanded). Watch serial for brownout resets, camera-init failures,
and WiFi drops — all three mean the 5V rail sagged under load. Check
the server side too: one `snapshotId` per interval (no gaps, no
dupes), a frame per camera period, and `appliedConfigRev` tracking the
sent config rev.

## Symptom table

| Symptom | First check |
|---|---|
| Won't boot after wiring | GPIO12 (MTDI) must float LOW — confirm U1-6 is unconnected. Then IO0–GND link left on. |
| Boot loop / brownout reset | 5V rail under load; cable, pack charge, C2 solder. |
| Camera init fails | ribbon seating; PSRAM enabled; no wire on camera pins (firmware aborts tell you which). |
| ADC reads 0/4095 stuck | wrong server-side ends; sensor on 5V instead of 3V3; R6/C1 solder. |
| DHT NaN | 4.7k R1 present? 3V3 power? leads < 1 m? pump EMI — reroute. |
| Pump never runs | gate node 0/3.3V on command? flyback orientation (D1 K→PUMP_5V)? separate pump supply ground shared? |
| Light never latches | GPIO4 gate drive? strip polarity (+5V common)? server actually sending `light` command? |
| Portal never opens | configured AP already provisioned — erase flash to force (`tools/erase.sh`; plain `pio run --target erase` cannot reset this board over UART) |
| Upload 4xx/5xx | URL/token constants, server allowlist for the effective `deviceId` (claimed pod ID, else build default); 4xx needs operator action (device will not portal-loop on it). |

## Limits

- OTA offers (`minFirmware` + `firmwareUrl`) upgrade the inactive slot
  and restart; no rollback slot, so keep the previous binary server-side
  for re-offer. The light latch does not survive a reboot.
- Pump doses cap at 30 s by contract; the server also clamps.
- Erasing NVS also clears the assigned device ID and boot count — the
  unit returns unclaimed and must be re-claimed by the server.
- Beyond the `health` telemetry block, diagnosis is serial-only.

## Erase / recover

```bash
tools/erase.sh /dev/ttyUSB0 && pio run --target upload
```

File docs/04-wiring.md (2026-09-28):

# Wiring and bring-up

## Wire table (module header → carrier)

| U1 | Goes to | Wire |
|---|---|---|
| 5V (1, 16) | XL6009 5V out, pump +, LED strip + | red, star at U1 |
| GND (3, 13, 15) | common ground star | black |
| 3V3 (11) | J1-1, J2-1, J3-1, U2-VDD | orange |
| GPIO13 (8) | J2-2 soil AO | yellow |
| GPIO14 (10) | R6 → J3-2 light AO | yellow |
| GPIO12 (6) | unconnected — MTDI safety (float + weak pulldown = LOW) | — |
| GPIO33 (14) | J1-2 water AO; R9 to GND | yellow |
| GPIO15 (12) | U2-DATA; R1 to 3V3 | green |
| GPIO2 (2) | R2 gate network | blue |
| GPIO4 (4) | R4 gate network | blue |
| IO0 (9) | R8 to 3V3 + SW1 to GND | — |
| U0RXD (5), U0TXD (7) | J4 PROG header to flashing adapter (crossed: adapter TX → J4-1, adapter RX ← J4-2) | — |

## J4 PROG header (1×4, west of U1)

| J4 | Net | Goes to |
|---|---|---|
| 1 | U0RXD | U1-5 (GPIO3); adapter TX |
| 2 | U0TXD | U1-7 (GPIO1); adapter RX |
| 3 | GND | ground star |
| 4 | +5V | 5V rail (powers the module while flashing) |

Straight 1:1 copper to U1 (no crossings). Flash with IO0 held LOW
(SW1), then release for SPI boot.

## Complete net list (every net, every node)

Notation: `U1-5` = carrier header U1 pin 5. `Q1-G/D/S` = gate/drain/source.
`D1-A/K` = anode/cathode. U2 pins are VDD/DATA/GND (pin 3 is NC, open).

| Net | Nodes |
|---|---|
| PACK+ | BLP673+ → CHG1 B+ (pin1); CHG1 OUT+ (pin3) → F1-1; F1-2 → XL6009 IN+ (F1 = pack overcurrent, 5 A hold polyfuse, 2920). Header order B+/B-/OUT+/OUT- — verify on module, clones vary |
| +5V | XL6009 5V out → U1-1, U1-16, J4-4, C2-1, C3-1; pump branch via F2 (PUMP_5V) → M1-1 + D1-K; LED branch via F3 (LED_5V) → D2-A |
| +3V3 | U1-11 (module AMS1117 out) → R7-1, J2-1, J3-1, U2-VDD, C4-1 (at U2), C5-1, R1-1, R8-1 |
| GND | star = OUT- → U1-3, U1-13, U1-15, J4-3, J1-3, J2-3, J3-3, U2-GND, C4-2 (at U2), C5-2, C6-2, C7-2, C8-2, C9-2, C10-2, Q1-S, Q2-S, R3-2, R5-2, R9-2, SW1-2, C1-2, C2-2, C3-2 |
| CELL_NEG | BLP673- → CHG1 B- (pin2), dedicated net — NEVER the GND star, or DW01A discharge protection is shorted out |
| U0RXD | U1-5 ↔ J4-1 (adapter TX) |
| U0TXD | U1-7 ↔ J4-2 (adapter RX) |
| BOOT_IO0 | U1-9 ↔ R8-2; U1-9 ↔ SW1-1 (SW1-2 → GND). R8-1 → +3V3 (10k PU = SPI boot HIGH) |
| PUMP_GATE | U1-2 (GPIO2) ↔ R2-1 |
| PUMP_GATE_Q | R2-2 ↔ R3-1 ↔ Q1-G (R3-2 → GND, 10k PD = OFF at boot, EMI-stiff) |
| PUMP_LO | Q1-D ↔ M1-2 ↔ D1-A |
| LIGHT_GATE | U1-4 (GPIO4) ↔ R4-1 |
| LIGHT_GATE_Q | R4-2 ↔ R5-1 ↔ Q2-G (R5-2 → GND, 10k PD = OFF at boot, EMI-stiff) |
| LED_LO | Q2-D ↔ D2-K |
| DHT_DATA | U1-12 (GPIO15) ↔ U2-DATA ↔ R1-2 (R1-1 → +3V3, 4.7k PU = MTDO HIGH) |
| TANK_VCC | +3V3 → R7-1; R7-2 ↔ J1-1 ↔ C6-1 (330 Ω series, dead-short → 10 mA) |
| WATER_AO | J1-2 ↔ R9-1 (R9-2 → GND, 10k PD; open probe reads ~0) ↔ R11-1 |
| WATER_ADC | R11-2 ↔ U1-14 (GPIO33) ↔ C10-1 (C10-2 → GND, 1k + 100n filter) |
| GPIO12_NC | U1-6 unconnected (float + weak pulldown = MTDI LOW, strapping safe) |
| SOIL_AO | J2-2 ↔ R10-1 |
| SOIL_ADC | R10-2 ↔ U1-8 (GPIO13) ↔ C9-1 (C9-2 → GND, 1k + 100n filter) |
| LIGHT_MOD_AO | J3-2 ↔ R6-1 |
| LIGHT_AO | U1-10 (GPIO14) ↔ R6-2 ↔ C1-1 (C1-2 → GND, 1k + 100n filter) |
| PUMP_RF | M1 + D1-K branch ↔ C11-1; C11-2 ↔ PUMP_LO (100n pump-terminal shunt) |

U2 pin 3: No-Connect, left open.

## Parts list (40 refs — matches schematic/bom.csv; U1A/U1B are units of U1)

| Ref | Value | Footprint | Function |
|---|---|---|---|
| U1 | ESP32-CAM | PinHeader_2x08_P2.54mm | AI-Thinker module (header) |
| U2 | DHT22 | PinHeader_1x04_P2.54mm_Vertical | temp + humidity (DHT11 symbol, pin-compatible) |
| J1 | WATER | PinHeader_1x03_P2.54mm | tank probe: 1 VCC, 2 AO, 3 GND |
| J2 | SOIL | PinHeader_1x03_P2.54mm | soil probe: 1 3V3, 2 AO, 3 GND |
| J3 | LIGHT-SENS | PinHeader_1x03_P2.54mm | light module: 1 3V3, 2 AO, 3 GND |
| J4 | PROG | PinHeader_1x04_P2.54mm | flash header: 1 RX, 2 TX, 3 GND, 4 5V |
| SW1 | BOOT | Button_Switch_THT:SW_PUSH-12mm | IO0 → GND for download mode |
| Q1, Q2 | IRLZ44N | TO-220-3 | low-side N-MOSFETs, pump + light |
| M1 | PUMP-5V-1A | Conn_01x02 (HDR2) | 5 V micro submersible pump, 1 A run / 2 A stall (off-board, header) |
| D1 | 1N5822 | DO-41 | pump flyback (K→PUMP_5V branch, A→PUMP_LO) — 3 A class for 2 A stall turn-off |
| D2 | GROW-LED-5V-20CM-2A | Conn_01x02 (HDR2) | full-spectrum strip 20 cm 2 A (A→LED_5V, K→LED_LO, off-board header) |
| R1 | 4.7k | R_0603 | DHT pull-up (MTDO-HIGH strapping) |
| R2, R4 | 220 | R_0603 | MOSFET gate stoppers |
| R3, R5 | 10k | R_0603 | gate pulldowns (OFF at boot, stiff vs humidity/EMI) |
| R6 | 1k | R_0603 | light-AO series (boot-PWM contention) |
| R7 | 330 | R_0603 | tank-probe VCC series (dead-short → 10 mA) |
| R8 | 10k | R_0603 | BOOT pull-up (SPI boot) |
| R9 | 10k | R_0603 | water-AO pulldown (open probe reads ~0 = EMPTY) |
| R10 | 1k | R_0603 | soil input series |
| R11 | 1k | R_0603 | water input series |
| C1 | 100n-50V | C_0603 | light-AO filter |
| C4 | 100n-50V | C_0603 | DHT VCC decoupling, at U2 |
| C5 | 10u-6V3 | C_0603 | +3V3 bulk at U1-11 |
| C6 | 100n-50V | C_0603 | tank header decoupling |
| C7 | 100n-50V | C_0603 | soil header decoupling |
| C8 | 100n-50V | C_0603 | light header decoupling |
| C9 | 100n-50V | C_0603 | soil input filter |
| C10 | 100n-50V | C_0603 | water input filter |
| C11 | 100n-50V | C_0603 | pump terminal RF shunt |
| C2 | 1000u-10V | CP_Radial_D8.0mm_P3.50mm | 5V bulk at module entry |
| C3 | 100n-50V | C_0603 | 5V ceramic at module entry |
| F1 | polyfuse 5 A hold | 2920 | pack+ → boost-in overcurrent (interlocked max ~5.5 A in at 3.0 V) |
| F2 | polyfuse 1.5 A hold | 1812 | pump branch (1 A run / 2 A stall) |
| F3 | polyfuse 2.5 A hold | 1812 | LED branch (20 cm 2 A strip × 1.25) |

Color code: red 5V, orange 3V3, black GND, yellow analog, green digital,
blue gate drive.

`storage` (SPIFFS) in `partitions.csv` is spare — the firmware persists
only to NVS (`nvs` partition) and never mounts SPIFFS.

## Bring-up order (do not skip)

1. **Bare module first.** Flash `factory` (07-operations), connect serial,
   confirm boot log and onboarding AP. No sensors yet.
2. **Power.** Pack → boost → 5V at U1-1/16 (4.9–5.2 V), 3V3 at U1-11.
   Confirm no heat, no reboot loop.
3. **One sensor at a time** (soil → light → water → DHT), checking each
   reading in the log before adding the next.
4. **Actuators with no load**: gate nodes switch 0/3.3 V on command;
   then connect pump, then LED strip.
5. **Soak**: 30 min of 15 s cycles, WiFi on, camera every 15 min.
   Watch `consecutive_failures` and heap.

## Hard rules

- No wire to camera pins (01-pinout forbidden list). The firmware aborts
  on overlap — treat an abort here as a wiring bug, not a firmware bug.
- SD slot stays empty and uninitialized.
- GPIO12 (U1-6) stays unconnected, **always** — it is the MTDI strapping
  pin and must float LOW at boot. If the board fails to boot after wiring,
  a stray connection on U1-6 is suspect #1.
- Keep pump/LED high-current loops short and away from DHT/sensor leads.

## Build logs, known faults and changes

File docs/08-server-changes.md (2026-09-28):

# Server-team requirements (GrowMate Pods)

Authoritative backend contract for the Pod device family. Device-side
behavior is specified in [06-api](06-api.md); this document lists what
the server must implement, store, and enforce.

## 1. Auth enforcement + 401 semantics

- Require `Authorization: Bearer <token>` on `POST /api/v1/sensors`
  and `POST /api/v1/camera` once per-device tokens ship. Tokens are
  build-time constants on the device; rotation is reflash-based (or OTA,
  §10) until a token-claim channel exists.
- Until then, gate on an explicit `deviceId` allowlist. Unknown IDs
  get `401`, never silent ingestion. Unclaimed birth IDs (`hardwareId`
  with default `deviceId`) should land in a review queue, not the void.
- `401` semantics: unknown, expired, or missing token. The device does
  NOT retry a 401 and does NOT reopen its onboarding portal over it —
  it keeps sensing and waits for the operator. Alert on repeated 401s
  from a known ID (token mismatch after reflash); alert on 401s from
  unknown IDs (spoofing/probing).

## 2. Status contract + Retry-After

| Status | When the server sends it |
|---|---|
| 2xx | accepted (also when there are no commands/config to return — always 200 with `{}` minimum) |
| 400 | malformed envelope (schema violation). Include a short error string; the device will not resend as-is |
| 401 | auth failure (§1) |
| 429 | rate limit hit (§6). MUST include a `Retry-After` header (seconds); the device honors it |
| 5xx | transient server failure; the device backs off and retries |

Never use redirects on these paths (the device does not follow them).
Keep response bodies under ~3 KB (device response buffer limit).

## 3. Ack / dedup handling

- Deduplicate telemetry on `snapshotId` (`"B<bootCount>-<seq>"`, unique
  per sample). Ingestion is at-least-once; double-POSTs of one id must
  not double-count. Note the fleet asymmetry: pods burn a `seq` on
  total-sensor-failure cycles (no POST), so pod gaps can mean failed
  reads; tech increments only when an envelope is built, so tech gaps
  mean queued-then-backfilled.
- Track per-device `acceptedCommandIds`. Re-deliver any command whose
  `id` has not been acked until it is acked or superseded by a newer
  command for the same actuator. Always attach a server-generated
  string `id` to every command.
- Use `currentState.{pumpEnabled,lightEnabled}` + `acceptedCommandIds`
  to distinguish "command lost" from "command applied, ack lost":
  if state already reflects the command, do not re-queue it.

## 4. ageMs time correction

The device has no RTC. The only sample-timing truth is
`ageMs` (sampling-to-POST latency, ms ≥ 0):

```
sampleTime = receivedAt - ageMs
```

Store `sampleTime`, not arrival time. Clamp absurd values
(`ageMs` larger than the report interval × 3, floor 45 s) and flag the
sample. Note: `ageMs` includes the WiFi join (up to 12 s) by design —
worst case ~28 s at a 10 s interval, inside the clamp, but tight.

## 5. Percent-computation ownership + calibration storage

The device sends RAW-ONLY analog entries (`{kind, unit, raw}`,
0–4095); percent mapping is server-owned, per probe, per install:

| Channel | Store per device | Mapping notes |
|---|---|---|
| water | `EMPTY` (probe in air), `FULL` (submerged) raw | rising scale |
| soil | `DRY` (air), `WET` (saturated soil) raw | rising scale |
| light | `DARK` (covered), `BRIGHT` (canopy under grow light) raw | INVERTED (dark ≈ 4095) |

Storage API needs:

- Per-device calibration record: `{channel, lowLabel, lowRaw,
  highLabel, highRaw, updatedAt}` plus write path (ops console or API)
  and audit of who changed it.
- Linear interpolation between the stored ends, clamped to 0–100%.
  Moving a probe or changing its supply invalidates its ends —
  require recalibration, do not silently keep stale ends.
- Analog entries carry `raw` only (no device-side percent field).
  DHT entries (`temperature` °C, `air` %RH) arrive native and need
  no mapping.

## 6. Config push schema + rev discipline

- Response field `config: {rev: int, reportIntervalSec: int}`.
  `rev` strictly increasing per device; `reportIntervalSec` 10–3600 s.
- The device persists rev + interval, applies the interval to the
  sensor cycle, and echoes `appliedConfigRev`. Never re-send a
  `rev <= appliedConfigRev`. Validate 10–3600 server-side before send.
- Camera period is NOT configurable (build-time 900 s); do not attempt
  to pace imaging via `reportIntervalSec`. Note the coupling: with an
  interval above 900 s the camera fires every cycle (one frame per
  interval), not every 900 s.

## 7. Rate limits

Enforce per-device limits and answer with `429` + `Retry-After`:

| Channel | Suggested limit |
|---|---|
| sensors POST | not more often than the device's effective interval (burst allowance ~3) |
| camera POST | at most 1 frame per 5 min per device |
| bytes | reject camera bodies over ~512 KB with `400` |

Rate-limit by authenticated `deviceId`, not by IP (many pods share one
egress). Log sustained 429s per device — a healthy pod never hits them.

## 8. maxPumpMs agreement

The device cap is 30 s (`0 < durationMs <= 30000`, water channel must
read). The server MUST ALSO clamp: never queue `durationMs > 30000`,
never queue a pump command when the last water reading is missing or
stale (> 3 intervals old). A pump dose is fire-and-forget once sent —
the one-shot runs on-device even if connectivity drops.

## 9. Health ingestion

Ingest `health.{heapFree, rssi, uptimeS, bootCount, resetReason,
dhtFails, adcFails}` on every POST. Suggested alerts:

| Signal | Threshold |
|---|---|
| `bootCount` increments without OTA | power/brownout — check pack + cabling |
| `rssi` | `< -75 dBm` sustained — AP placement |
| `heapFree` | trending down across boots — leak, capture a report |
| `dhtFails` / `adcFails` | rising — sensor wiring/EMI (see 07-operations) |
| `resetReason` | anything except the `power-on` baseline — investigate (`sw` after OTA is normal; `panic`/`brownout`/`power-glitch`/`wdt`/`task-wdt`/`int-wdt`/`cpu-lockup` always are) |

Dashboard per device: last `snapshotId`, `appliedConfigRev` vs sent
`rev` (drift = config not landing), pending unacked command ids.

## 10. Claim flow (live) + OTA (live)

- Claiming: every unit is born with its WiFi MAC as `hardwareId`
  (uppercase hex, always sent). A unit with no assigned ID reports
  `deviceId` = build default and is ingested as *unclaimed*.
- To claim/rename: answer any sensor POST with
  `claim: {deviceId: "<pod-id>"}` (`[A-Za-z0-9_-]`, ≤31 chars). The
  device validates, persists (NVS), and reports the new `deviceId` from
  the next POST. Re-sending the same ID is a no-op. Onboarding AP name
  follows the effective ID, so it changes once at claim time.
- Unclaim = erase flash (`tools/erase.sh`); the unit returns to
  its birth identity and must be re-claimed.
- OTA is live: send `minFirmware: "x.y.z"` + `firmwareUrl: "https://…"`
  to offer an update. The device upgrades only when the offered version
  is newer than its own, never mid pump-dose, then restarts. Rules:
  host a complete signed-by-TLS `.bin` built from this repo (same
  partition scheme — ota slots are 1.5 MB, images must fit); keep old
  binaries for rollback-by-reoffer; do NOT gate telemetry on version.
- Onboarding AP password is per-device (`GrowMate-<last6 of MAC>`,
  WPA2). There is no shared password anymore; the portal itself is still
  plaintext HTTP — commission in a trusted location (see 07-operations).

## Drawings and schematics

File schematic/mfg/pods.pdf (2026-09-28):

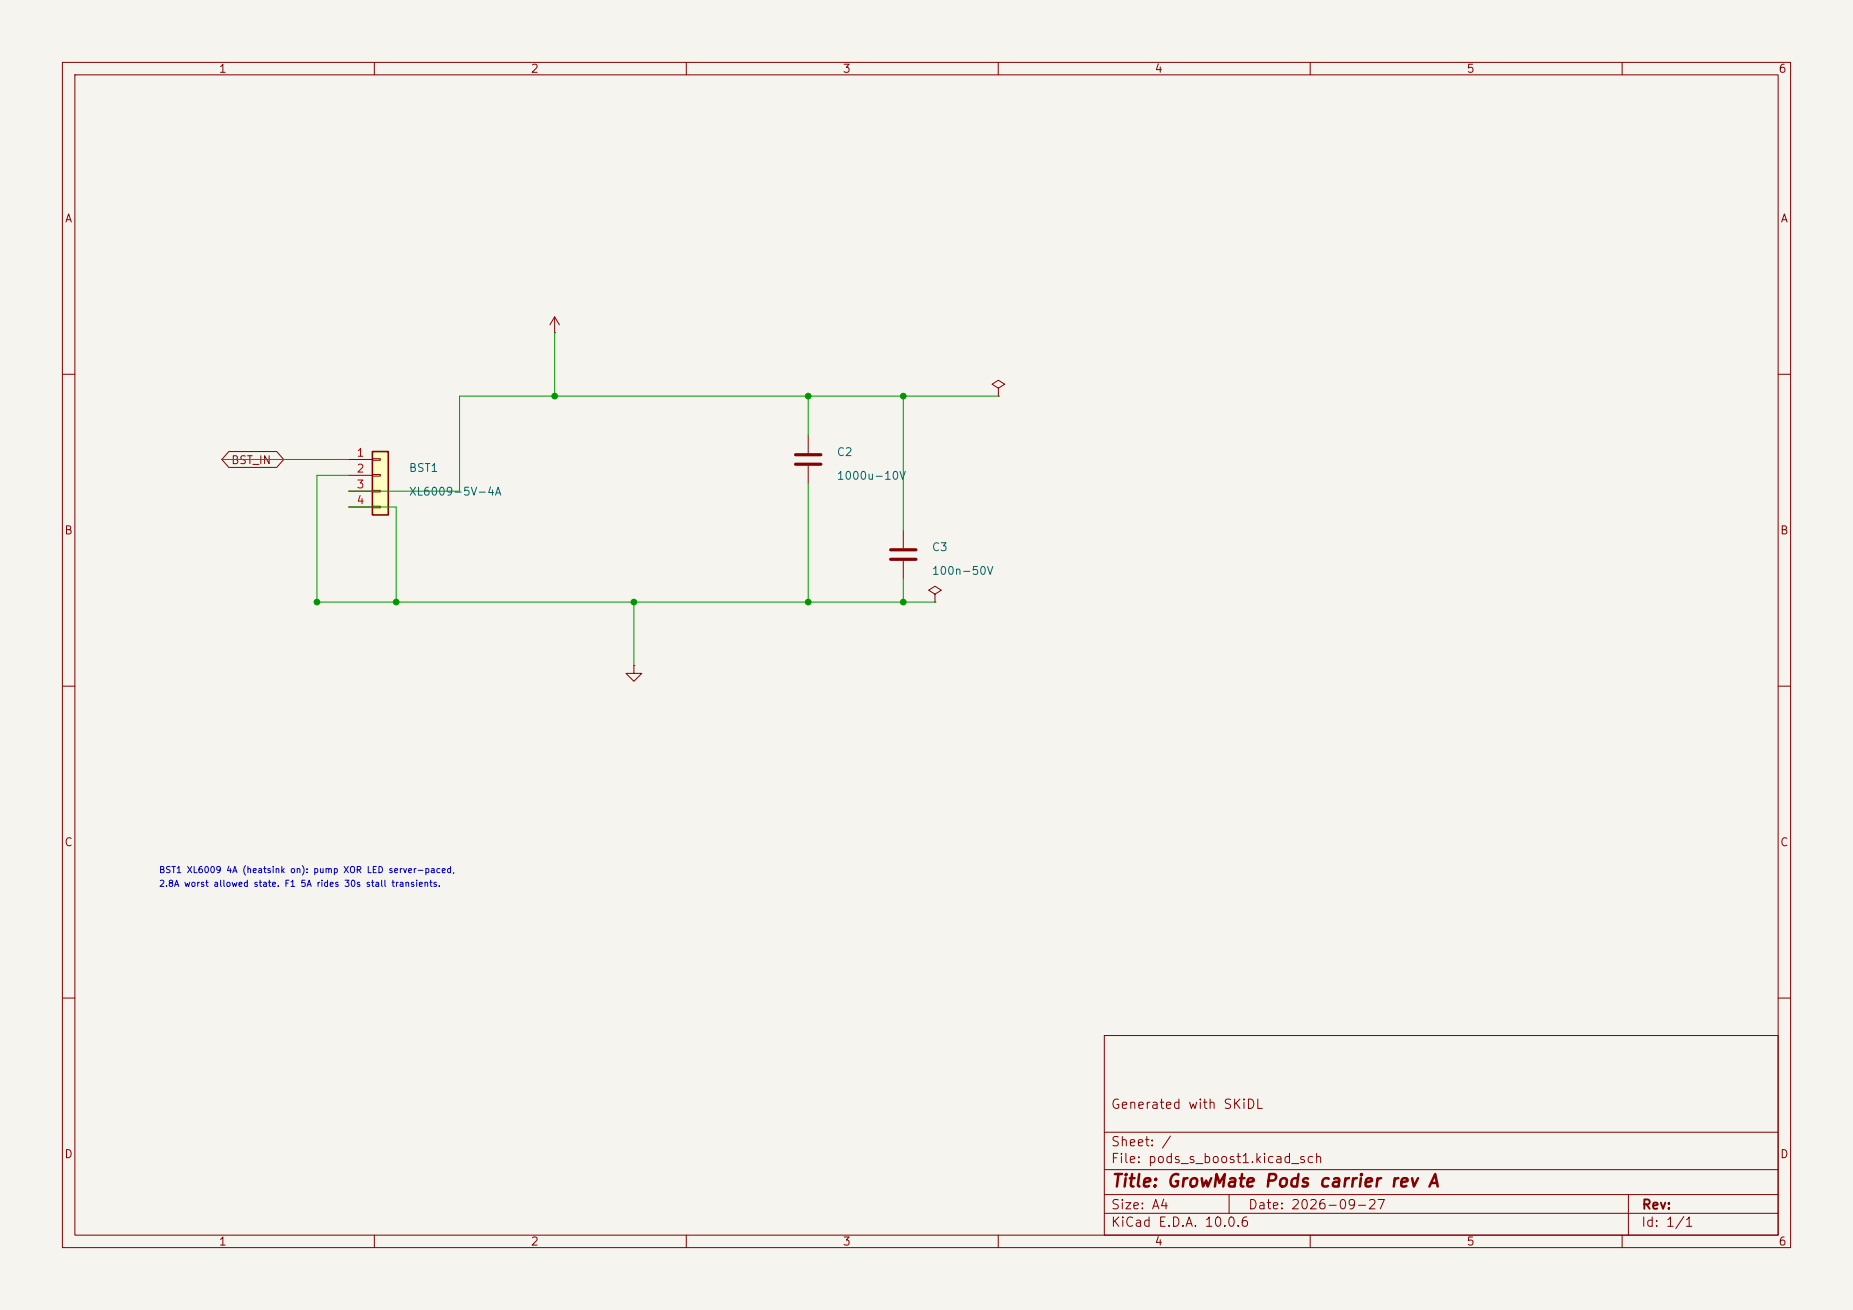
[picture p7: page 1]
D Date: 2026-09-27; Size: A4; Rev:; BST1; XL6009-5V-4A BST_IN

2.8A worst allowed state. F1 5A rides 30s stall transients. BST1 XL6009 4A (heatsink on): pump XOR LED server-paced,

Generated with SKiDL

Sheet: /
File: pods_s_boost1.kicad_sch
Title: GrowMate Pods carrier rev A
KiCad E.D.A. 10.0.6

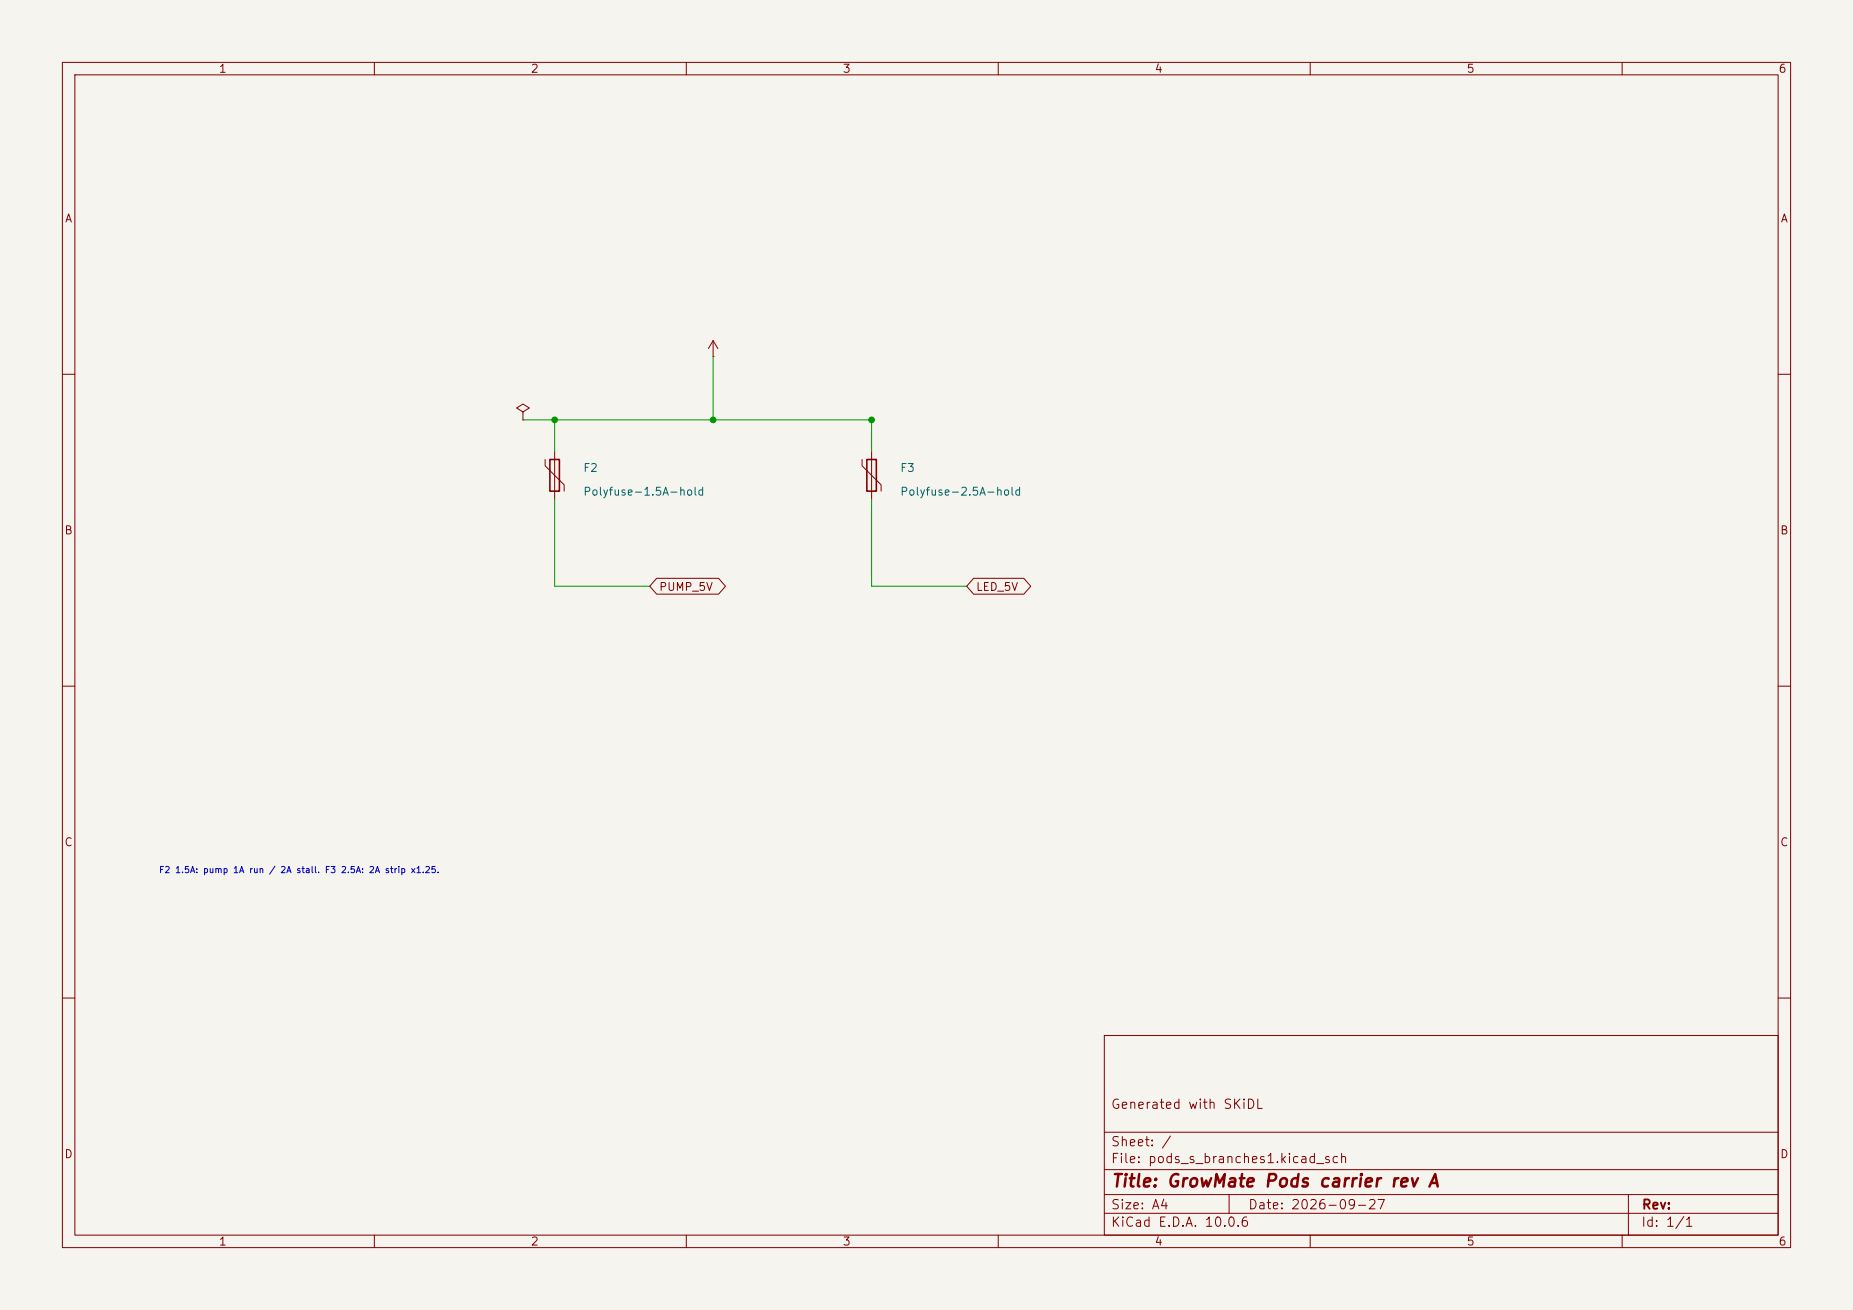
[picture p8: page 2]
D Date: 2026-09-27; F3Polyfuse-2.5A-hold; F2Polyfuse-1.5A-hold PUMP_5V; LED_5V

F2 1.5A: pump 1A run / 2A stall. F3 2.5A: 2A strip x1.25.

Generated with SKiDL

Sheet: /
File: pods_s_branches1.kicad_sch
Title: GrowMate Pods carrier rev A

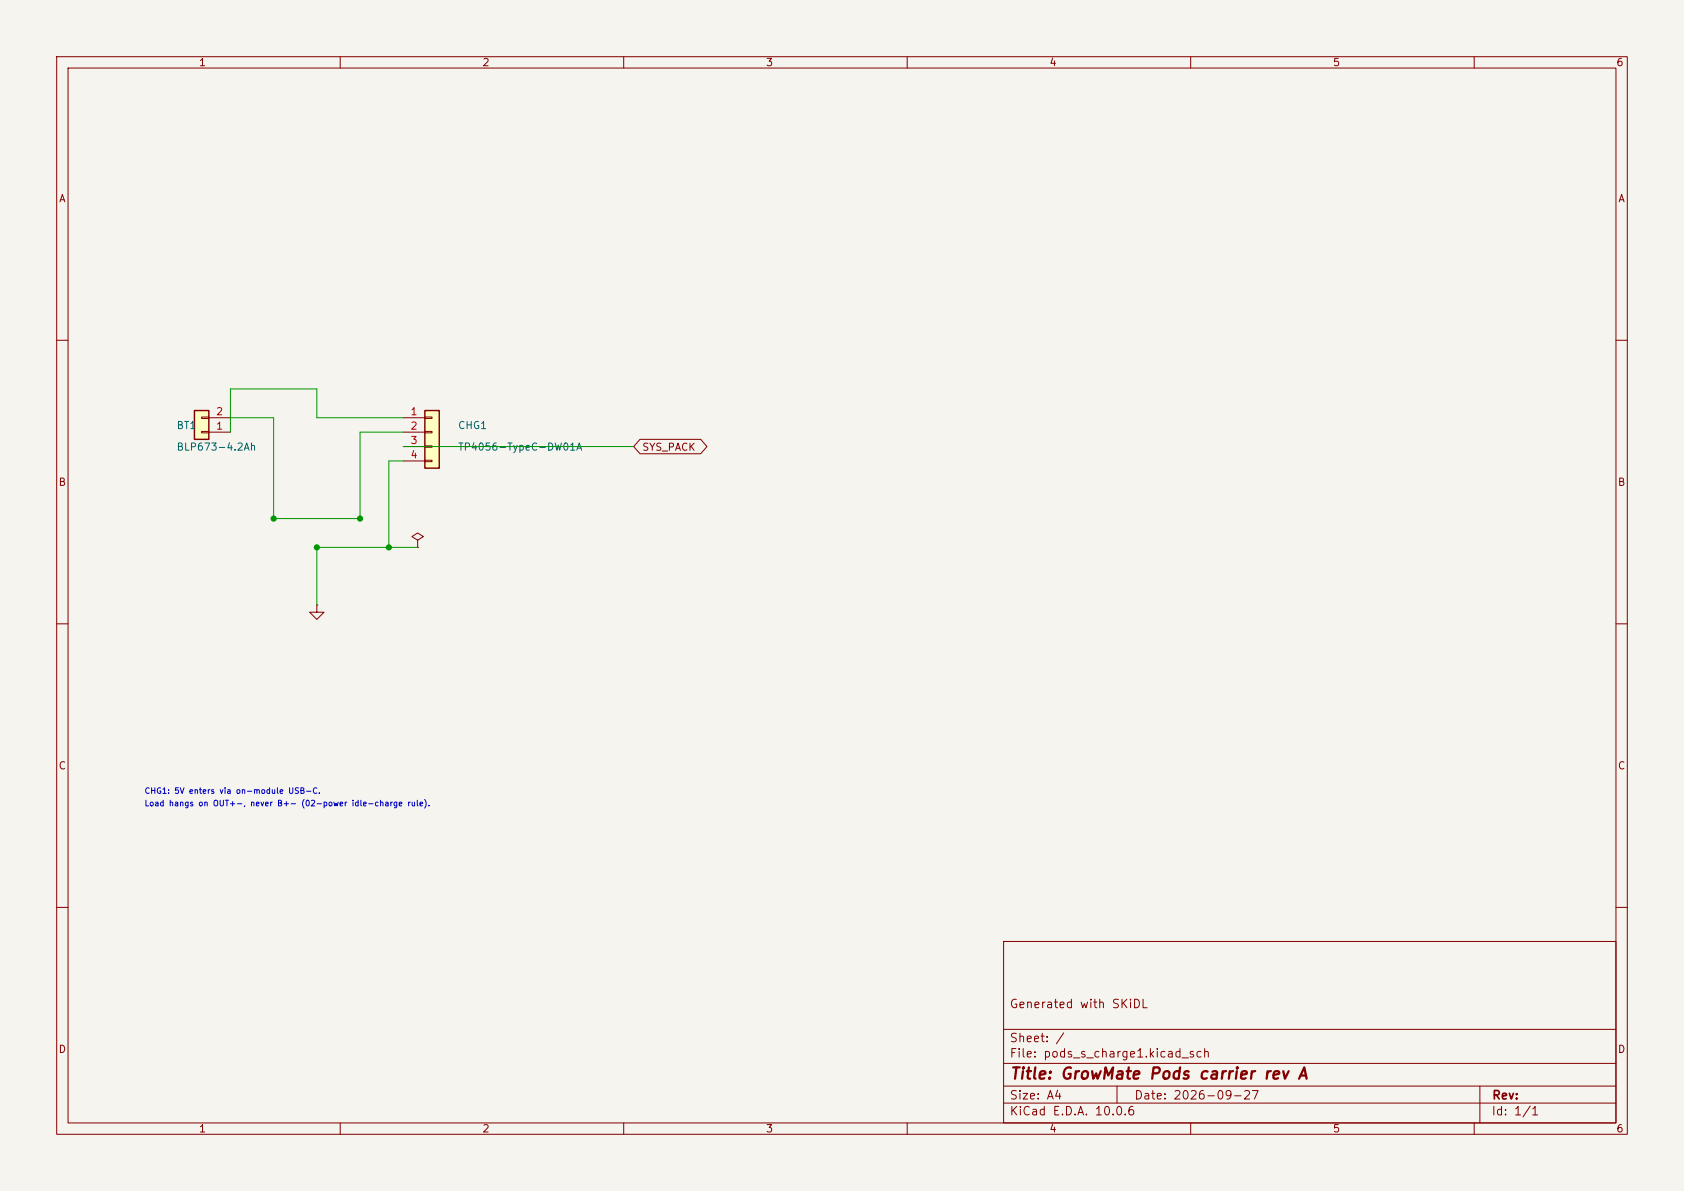
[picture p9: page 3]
D Date: 2026-09-27; CHG1; TP4056-TypeC-DW01A 1; 2 BT1 BLP673-4.2Ah; SYS_PACK

Load hangs on OUT+-, never B+- (02-power idle-charge rule). CHG1: 5V enters via on-module USB-C.

Generated with SKiDL

Sheet: /
File: pods_s_charge1.kicad_sch
Title: GrowMate Pods carrier rev A

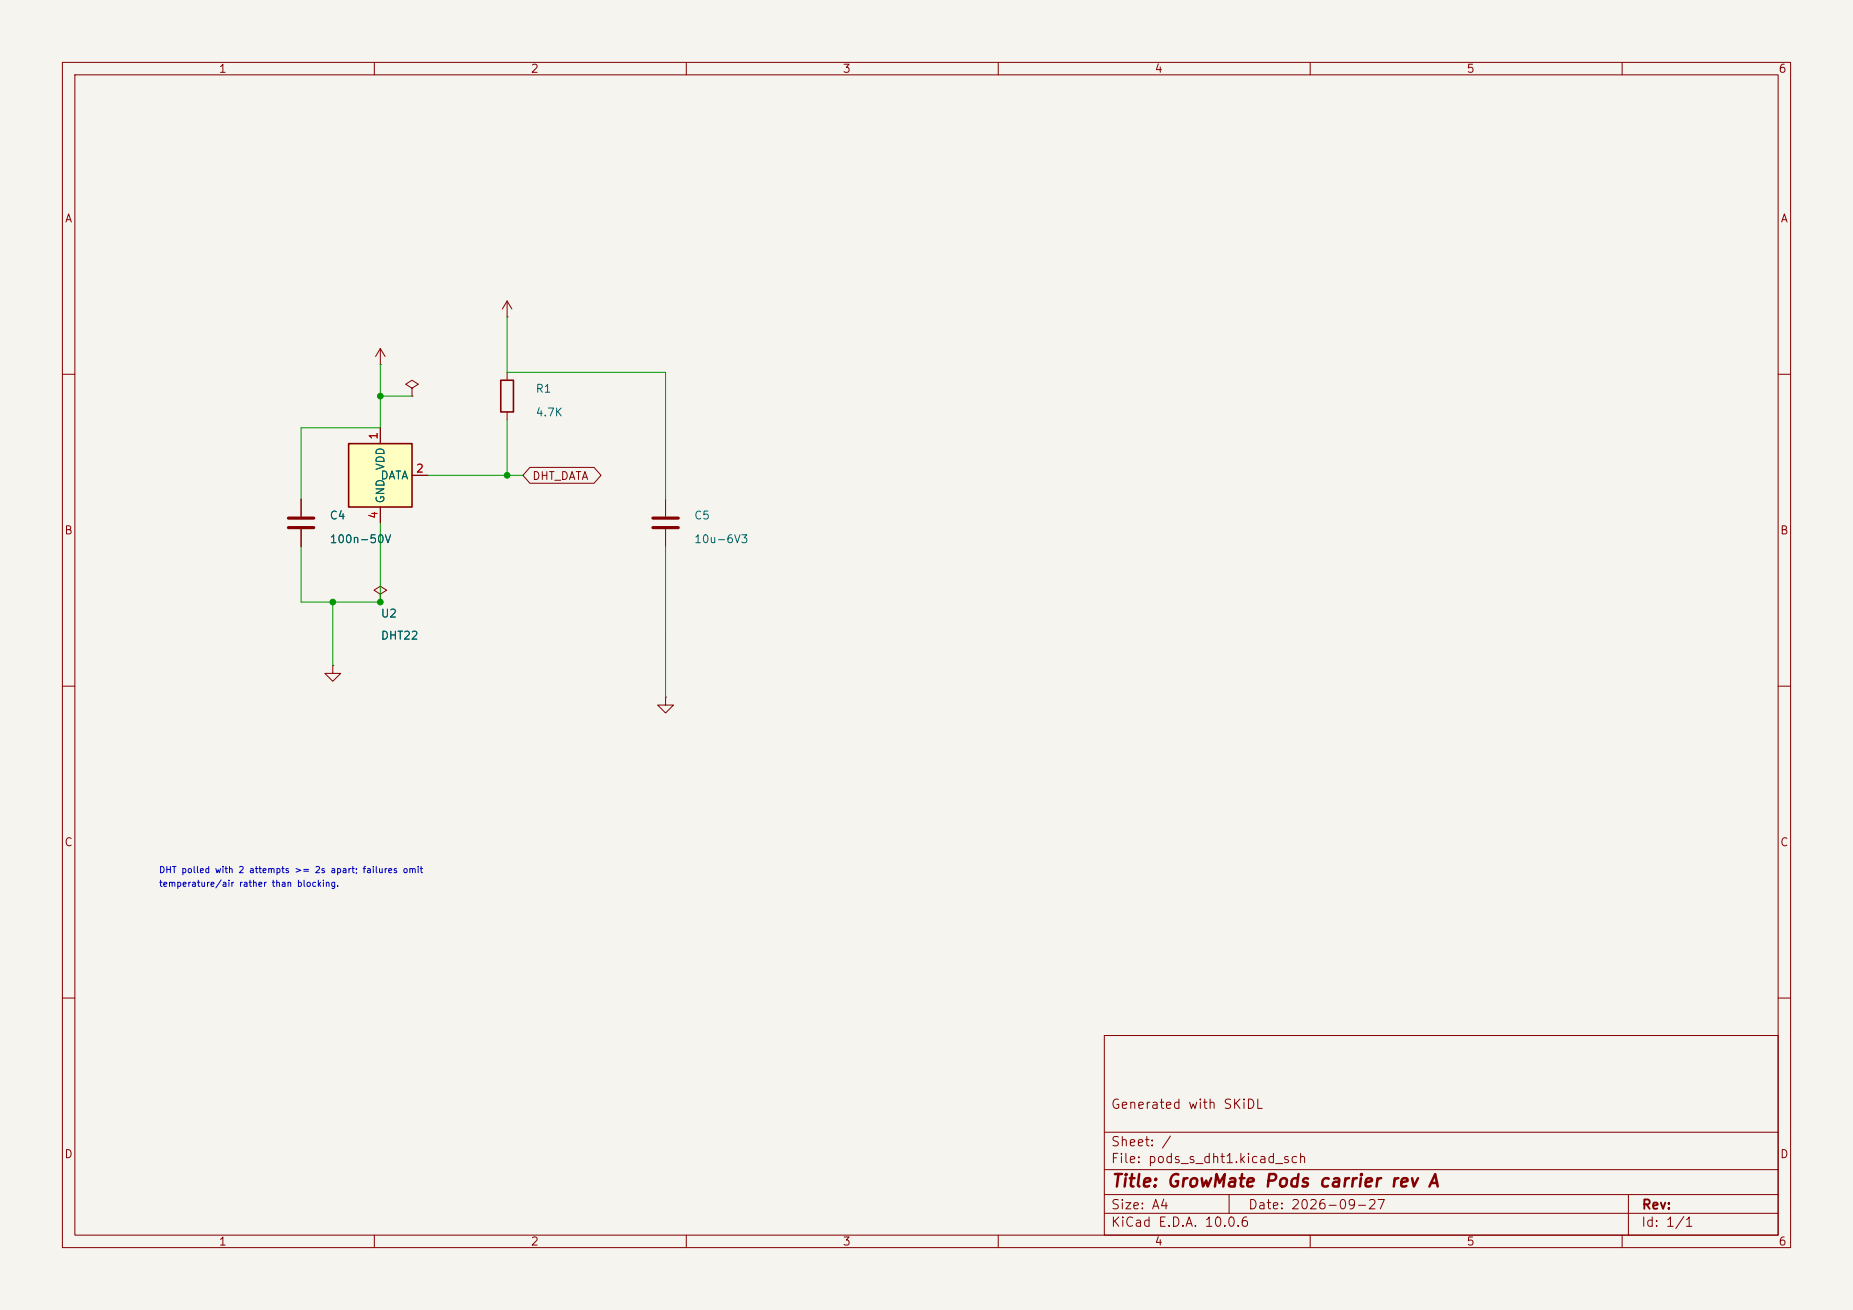
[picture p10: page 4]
D Date: 2026-09-27; 100n-50VVDD; 1 DATA 2 GND; 4 U2DHT22 C5; 10u-6V3 DHT_DATA; 100n-50VU2DHT22 VDD

temperature/air rather than blocking. C4

DHT polled with 2 attempts >= 2s apart; failures omit

Generated with SKiDL

Sheet: /
File: pods_s_dht1.kicad_sch
Title: GrowMate Pods carrier rev A

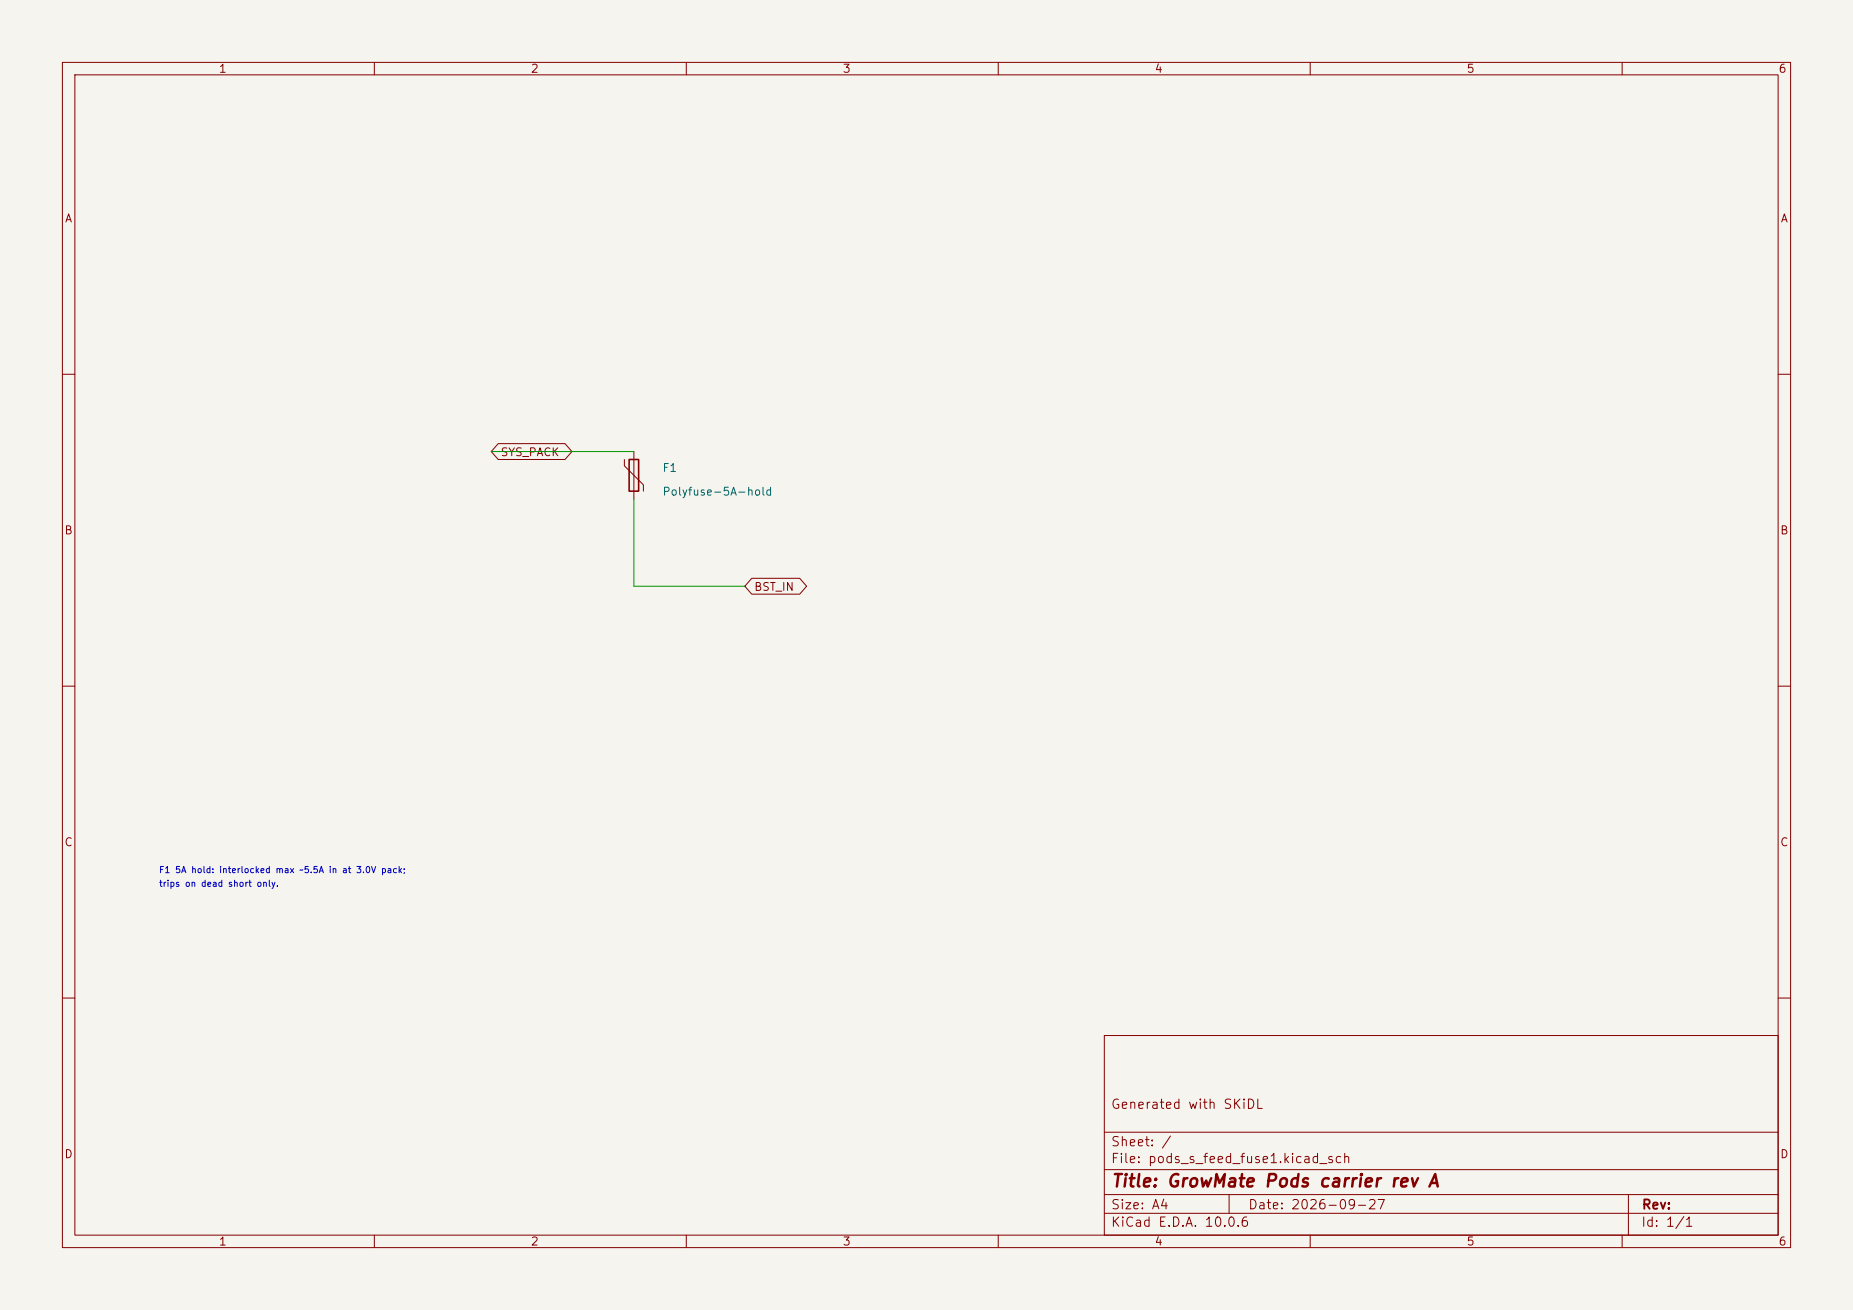
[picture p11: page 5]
D Date: 2026-09-27; F1Polyfuse-5A-hold SYS_PACK; BST_IN

trips on dead short only. F1 5A hold: interlocked max ~5.5A in at 3.0V pack;

Generated with SKiDL

Sheet: /
File: pods_s_feed_fuse1.kicad_sch
Title: GrowMate Pods carrier rev A

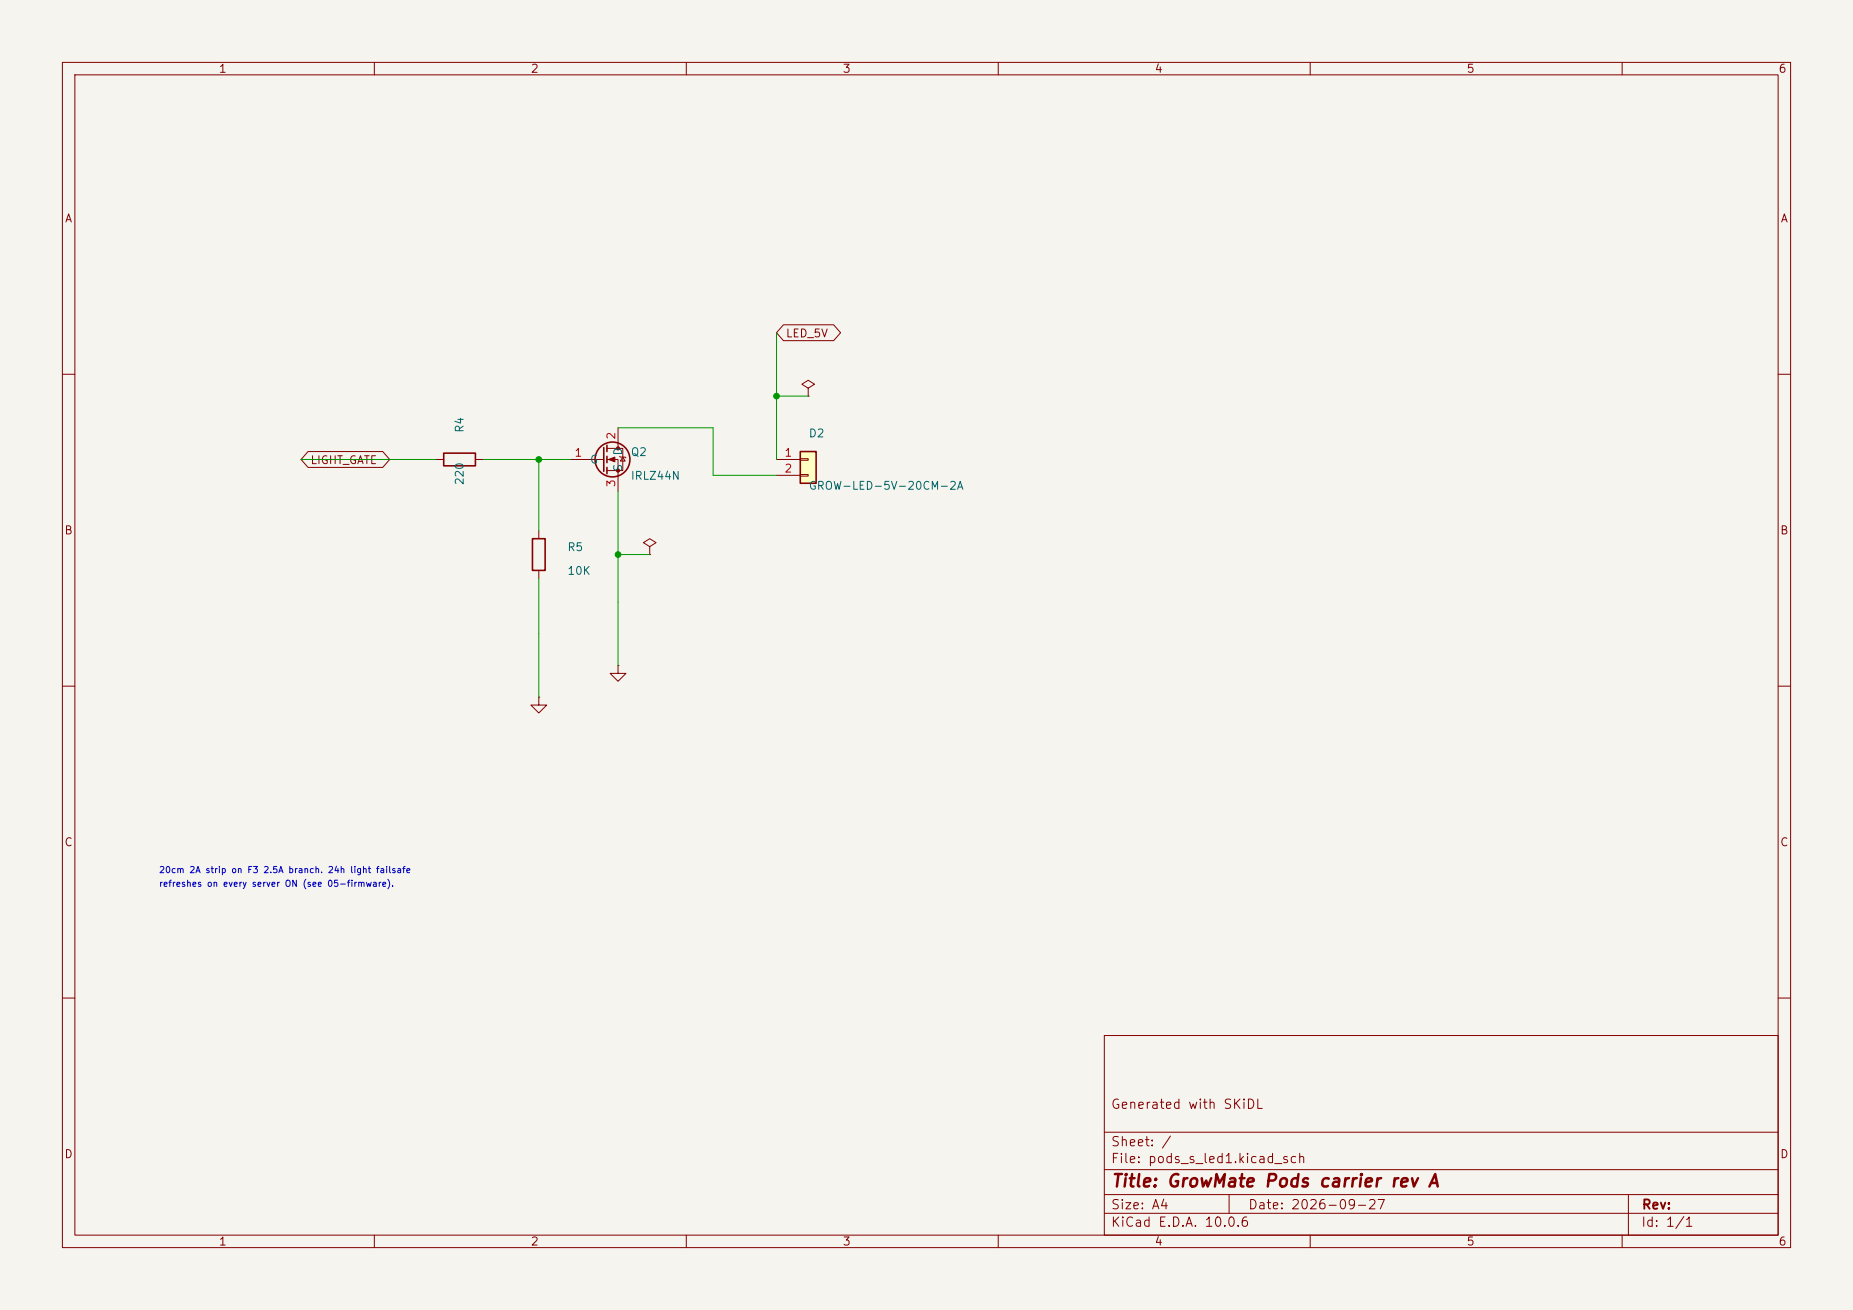
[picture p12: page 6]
D Date: 2026-09-27; D2GROW-LED-5V-20CM-2A R5; IRLZ44N; LED_5V; LIGHT_GATE

Generated with SKiDL R4 220

refreshes on every server ON (see 05-firmware). 20cm 2A strip on F3 2.5A branch. 24h light failsafe

Sheet: /
File: pods_s_led1.kicad_sch
Title: GrowMate Pods carrier rev A

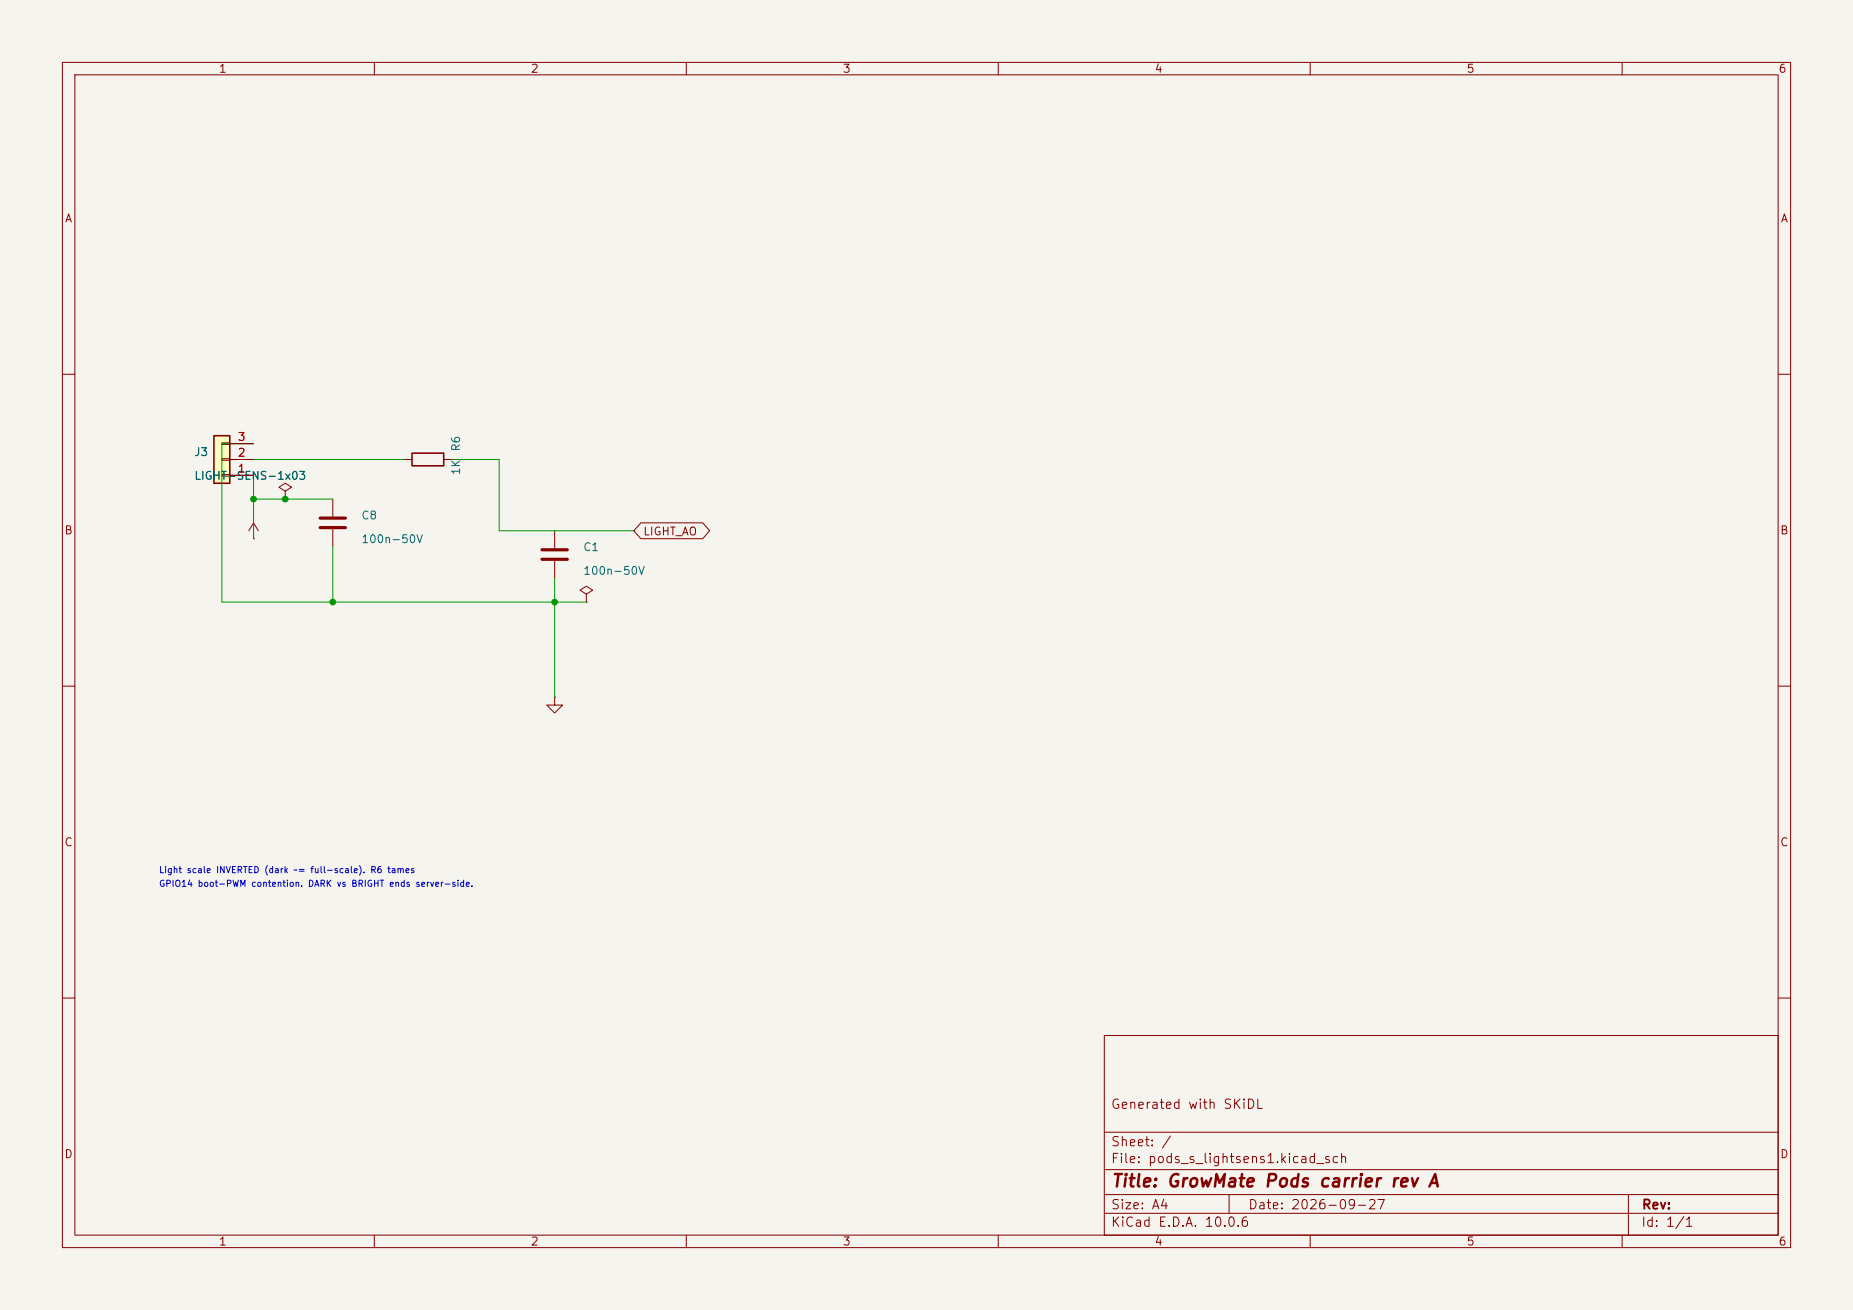
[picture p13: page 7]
D Date: 2026-09-27; LIGHT-SENS-1x03; LIGHT_AO; J3 LIGHT-SENS-1x03 1

Light scale INVERTED (dark ~= full-scale). R6 tames GPIO14 boot-PWM contention. DARK vs BRIGHT ends server-side.

Generated with SKiDL

Sheet: /
File: pods_s_lightsens1.kicad_sch
Title: GrowMate Pods carrier rev A

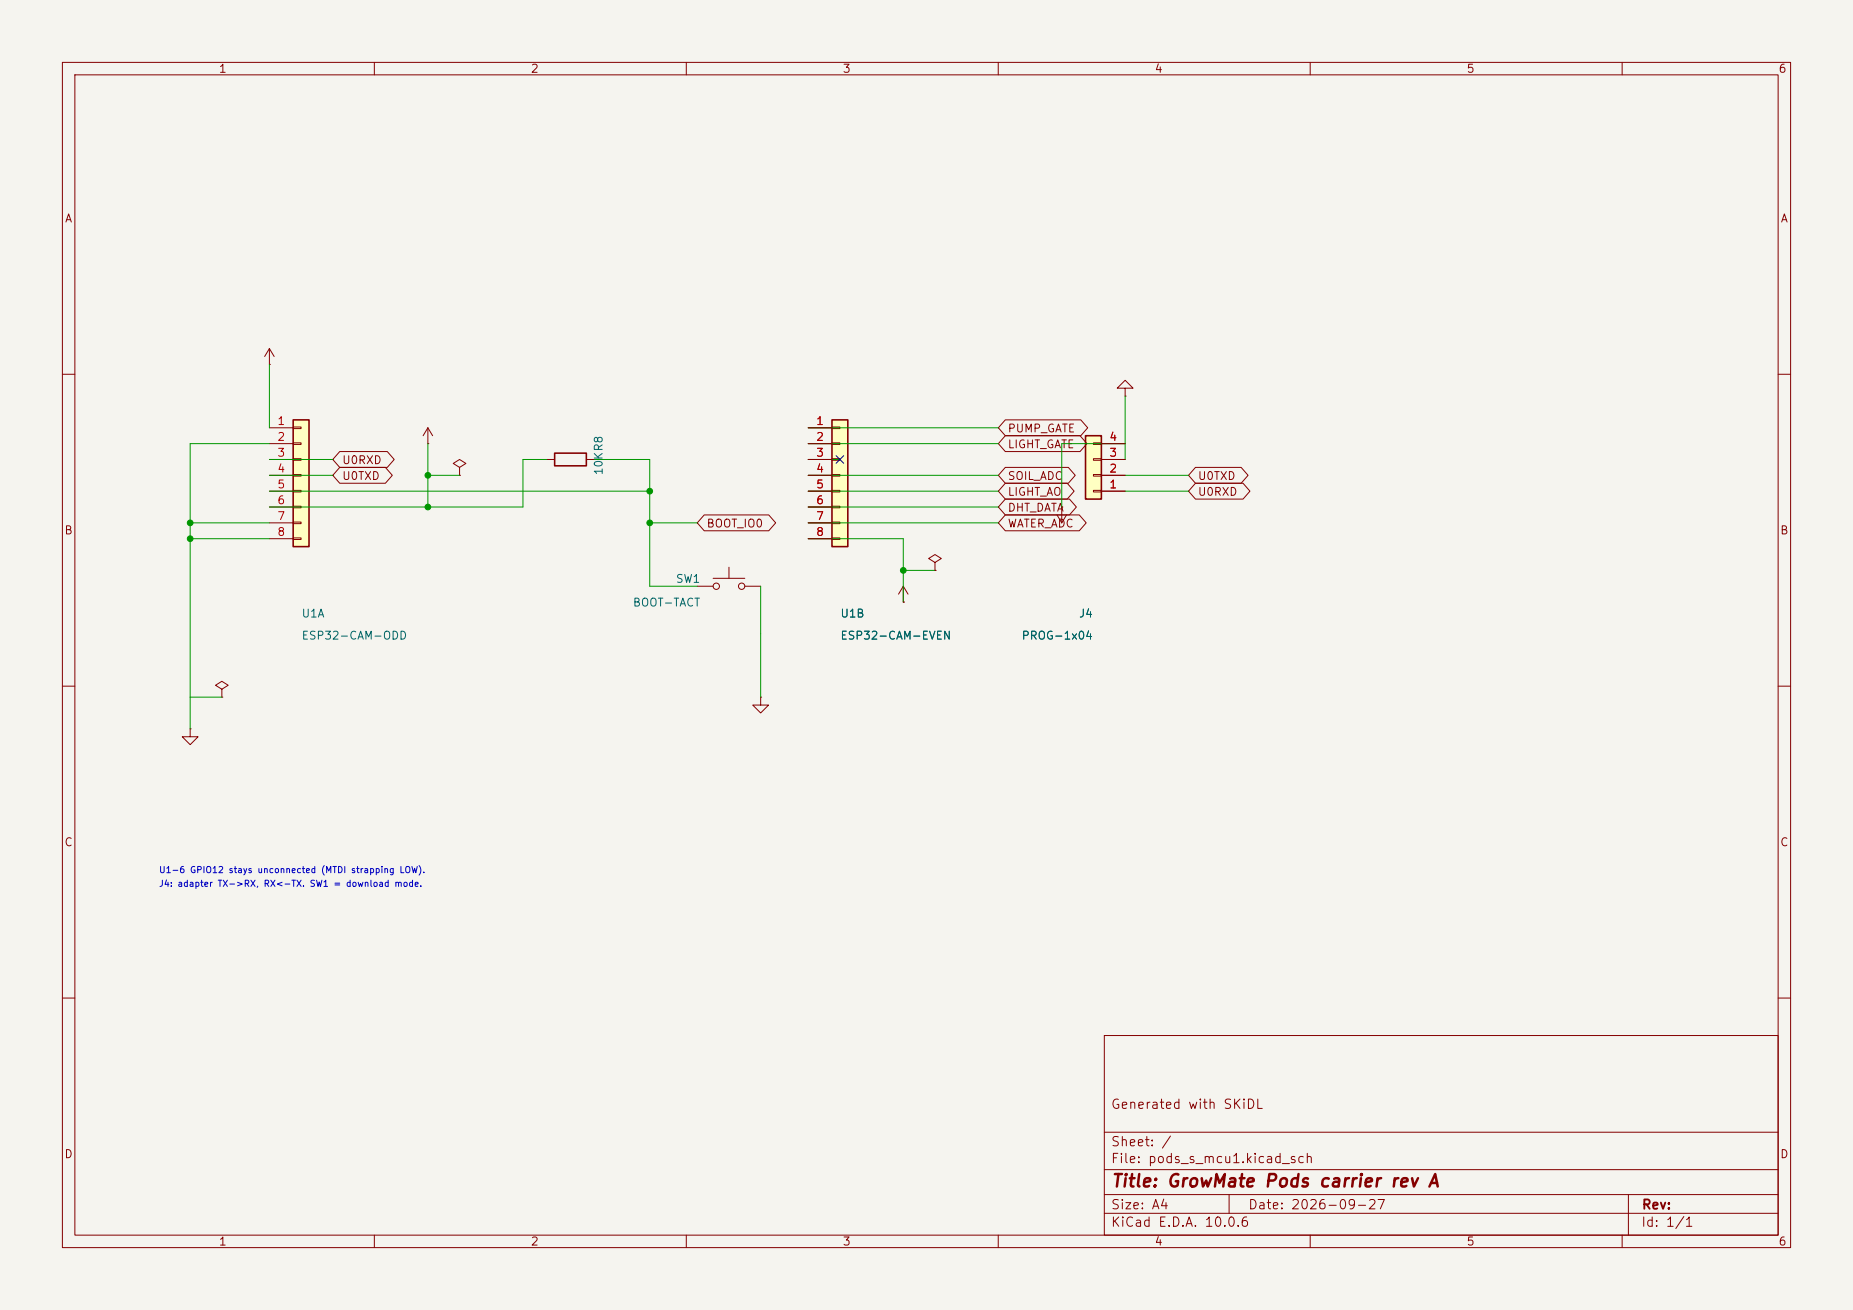
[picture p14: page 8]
D Date: 2026-09-27; ESP32-CAM-EVEN; J4 PROG-1x04 R8 10K; U1A ESP32-CAM-ODD; SW1 BOOT-TACT; LIGHT_GATE PUMP_GATE U0TXD; WATER_ADC; DHT_DATA; LIGHT_AO; U0RXD; U0TXD U0RXD; SOIL_ADC; BOOT_IO0; J4: adapter TX->RX, RX<-TX. SW1 = download mode. U1-6 GPIO12 stays unconnected (MTDI strapping LOW).; J4 PROG-1x04

Generated with SKiDL

Sheet: /
File: pods_s_mcu1.kicad_sch
Title: GrowMate Pods carrier rev A

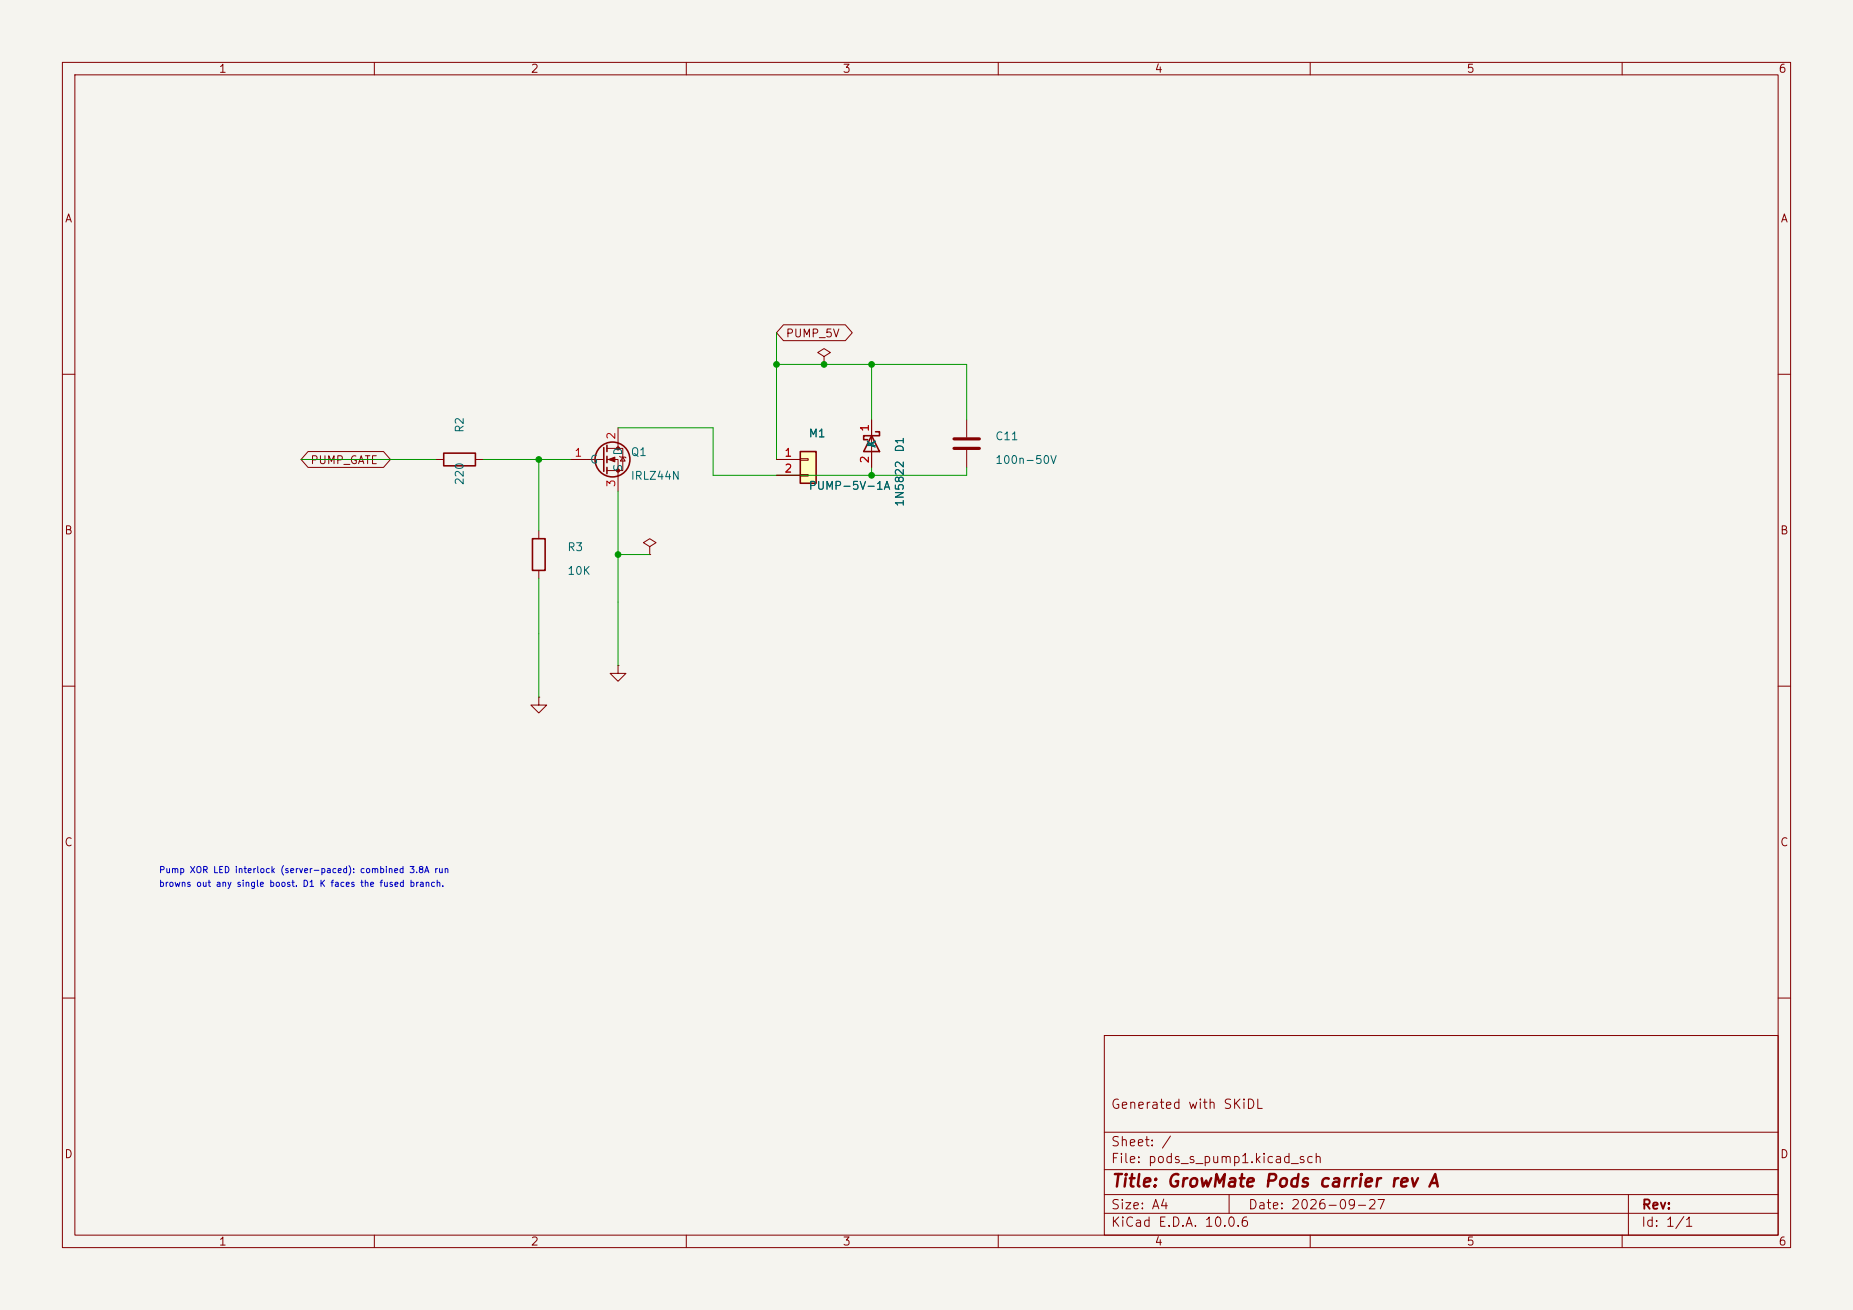
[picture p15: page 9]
D Date: 2026-09-27; M1 PUMP-5V-1A; IRLZ44N R2 220; A 2 D1 1N5822PUMP_GATE PUMP_5V; browns out any single boost. D1 K faces the fused branch.; M1 PUMP-5V-1A 1

Pump XOR LED interlock (server-paced): combined 3.8A run

Generated with SKiDL

Sheet: /
File: pods_s_pump1.kicad_sch
Title: GrowMate Pods carrier rev A

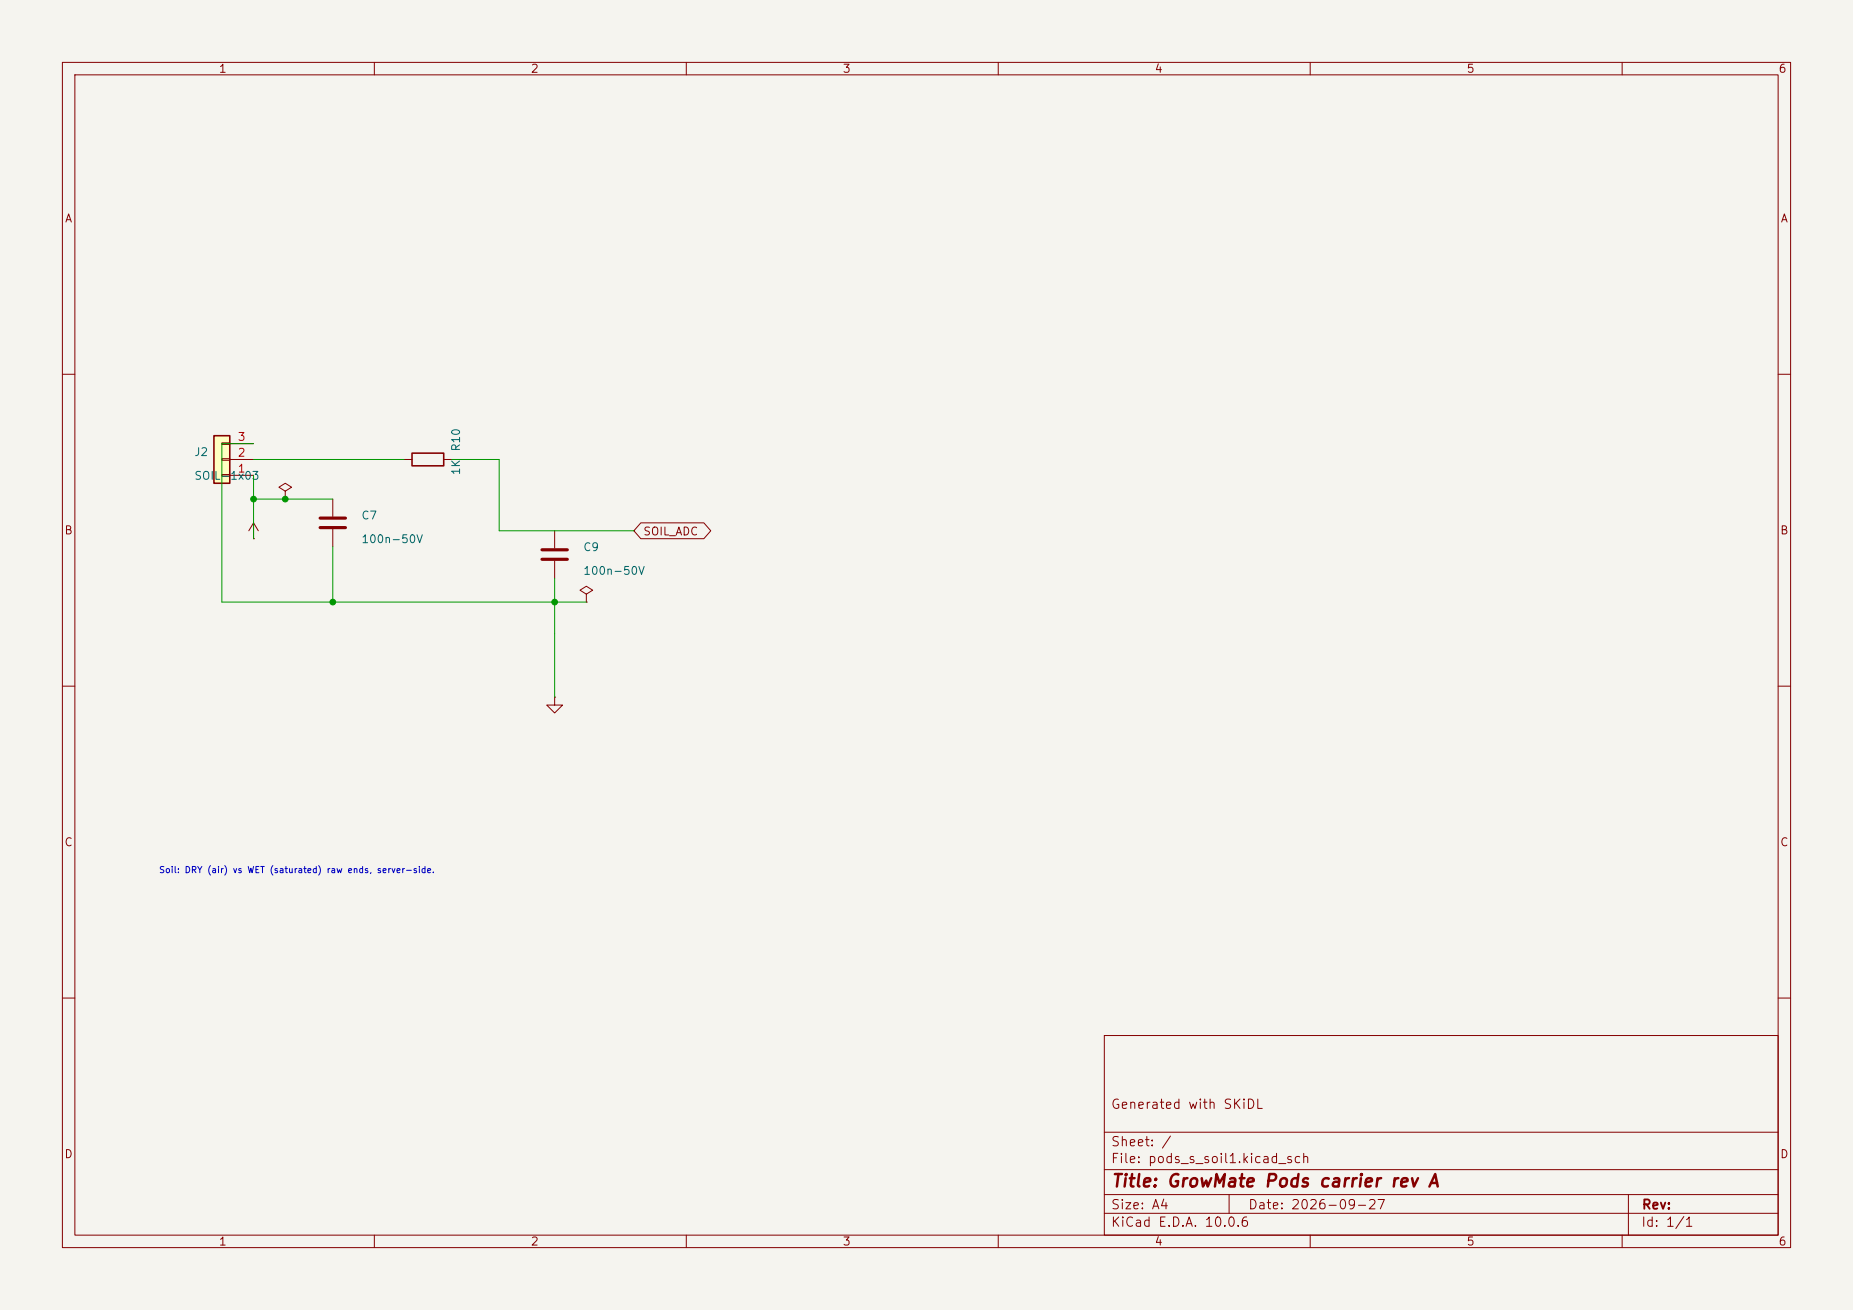
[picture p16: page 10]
D Date: 2026-09-27; SOIL-1x03; SOIL_ADC

Soil: DRY (air) vs WET (saturated) raw ends, server-side.

Generated with SKiDL

Sheet: /
File: pods_s_soil1.kicad_sch
Title: GrowMate Pods carrier rev A

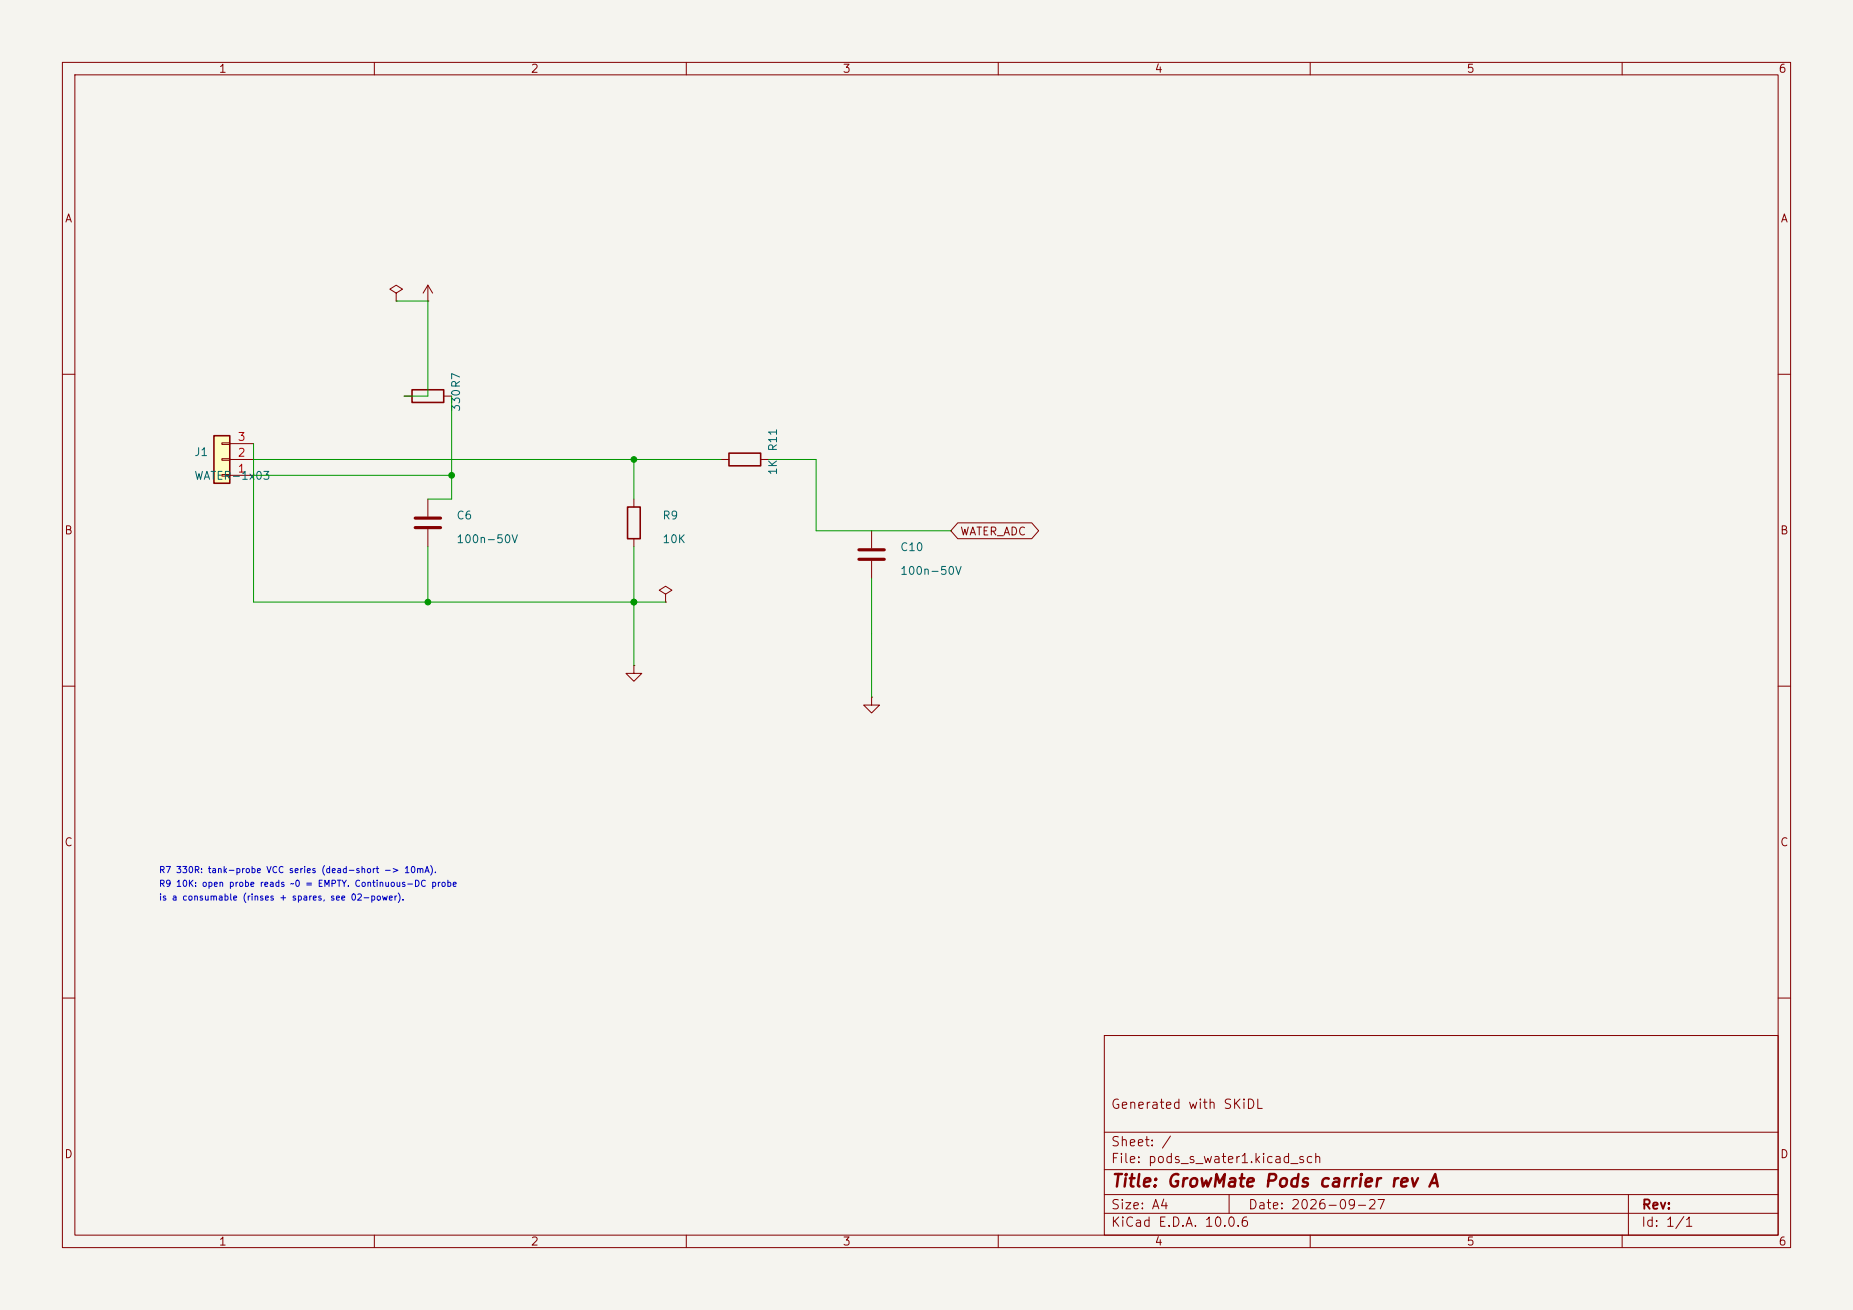
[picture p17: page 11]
D Date: 2026-09-27; J1WATER-1x03; WATER_ADC

is a consumable (rinses + spares, see 02-power). R9 10K: open probe reads ~0 = EMPTY. Continuous-DC probe R7 330R: tank-probe VCC series (dead-short -> 10mA).

Generated with SKiDL

Sheet: /
File: pods_s_water1.kicad_sch
Title: GrowMate Pods carrier rev A

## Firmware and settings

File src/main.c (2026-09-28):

#include <stdbool.h>
#include <stdint.h>

#include "actuators.h"
#include "api_client.h"
#include "app_build_config.h"
#include "app_config.h"
#include "board_profile.h"
#include "camera_service.h"
#include "device_identity.h"
#include "esp_check.h"
#include "esp_log.h"
#include "esp_task_wdt.h"
#include "esp_timer.h"
#include "freertos/FreeRTOS.h"
#include "freertos/task.h"
#include "main_logic.h"
#include "network_manager.h"
#include "nvs_flash.h"
#include "onboarding.h"
#include "ota_service.h"
#include "sensors.h"

#define WIFI_CONNECT_TIMEOUT_MS 12000
#define UPLOAD_RETRY_COUNT 2

static const char *TAG = "growmate";

static void delay_with_housekeeping(const board_profile_t *profile, uint32_t total_ms)
{
    const TickType_t step = pdMS_TO_TICKS(250);
    TickType_t remaining = pdMS_TO_TICKS(total_ms);

    while (remaining > 0) {
        actuators_tick(profile);
        esp_task_wdt_reset();
        TickType_t current_step = remaining > step ? step : remaining;
        vTaskDelay(current_step);
        remaining -= current_step;
    }
}

static esp_err_t upload_sensor_snapshot(app_config_t *config,
                                        const sensor_snapshot_t *snapshot,
                                        const board_profile_t *profile,
                                        ota_update_t *ota)
{
    device_commands_t commands = {0};
    ESP_LOGI(TAG, "Starting sensor cycle");

    esp_err_t err = ESP_FAIL;
    for (int attempt = 0; attempt < UPLOAD_RETRY_COUNT; ++attempt) {
        err = api_client_upload_sensor_data(config,
                                            snapshot,
                                            actuators_is_pump_enabled(),
                                            actuators_is_light_enabled(),
                                            &commands,
                                            ota);
        if (err == ESP_OK || err == ESP_ERR_INVALID_STATE) {
            break;
        }
        // Keep the pump safety net serviced even while backing off.
        delay_with_housekeeping(profile, 1500);
    }

    if (err == ESP_OK) {
        actuators_apply_commands(profile, &commands);
    }
    return err;
}

static esp_err_t upload_camera_image(const board_profile_t *profile, const app_config_t *config)
{
    if (!APP_CAMERA_ENABLED || !profile->has_camera) {
        return ESP_OK;
    }

    ESP_LOGI(TAG, "Starting camera cycle");
    esp_err_t err = camera_service_init(profile);
    if (err != ESP_OK) {
        return err;
    }

    camera_fb_t *fb = camera_service_capture();
    if (fb == NULL) {
        camera_service_deinit();
        return ESP_FAIL;
    }

    if (fb->format != PIXFORMAT_JPEG) {
        esp_camera_fb_return(fb);
        camera_service_deinit();
        return ESP_FAIL;
    }

    err = ESP_FAIL;
    for (int attempt = 0; attempt < UPLOAD_RETRY_COUNT; ++attempt) {
        err = api_client_upload_image_bytes(config, fb->buf, fb->len);
        if (err == ESP_OK || err == ESP_ERR_INVALID_STATE) {
            break;
        }
        actuators_tick(profile);
        esp_task_wdt_reset();
        vTaskDelay(pdMS_TO_TICKS(1500));
    }

    esp_camera_fb_return(fb);
    camera_service_deinit();
    return err;
}

void app_main(void)
{
    esp_err_t err = nvs_flash_init();
    if (err == ESP_ERR_NVS_NO_FREE_PAGES || err == ESP_ERR_NVS_NEW_VERSION_FOUND) {
        ESP_ERROR_CHECK(nvs_flash_erase());
        err = nvs_flash_init();
    }
    ESP_ERROR_CHECK(err);

    // The main loop legitimately blocks (12 s WiFi join, 45 s JPEG POST,
    // OTA download, indefinite portal). A 5 s watchdog would false-trip,
    // so subscribe app_main with a 60 s window; every blocking path
    // above feeds it at least once per second.
    ESP_ERROR_CHECK(esp_task_wdt_reconfigure(&(esp_task_wdt_config_t) {
        .timeout_ms = 60000,
        .idle_core_mask = (1 << 0) | (1 << 1),
        .trigger_panic = true,
    }));
    ESP_ERROR_CHECK(esp_task_wdt_add(NULL));

    app_config_t config;
    app_config_load(&config);
    app_config_sanitize(&config);
    config.boot_count++;
    bool boot_save_failed = false;
    if (app_config_save(&config) != ESP_OK) {
        // A failed boot-count save reuses the previous boot's snapshotIds
        // (B<boot>-<seq>), which the server dedups as duplicates. Retry
        // before the first POST; the boot still runs but may gap ingestion.
        ESP_LOGE(TAG, "Failed to save boot count, will retry before first POST");
        boot_save_failed = true;
    }

    const board_profile_t *profile = board_profile_get((board_profile_id_t) APP_BOARD_PROFILE);
    ESP_LOGI(TAG, "Starting %s for board %s", device_effective_id(&config), profile->display_name);

    ESP_ERROR_CHECK(network_manager_init());
    actuators_init(profile);
    sensors_init(profile);

    if (!app_config_is_complete(&config)) {
        ESP_LOGW(TAG, "Configuration incomplete, entering onboarding mode");
        ESP_ERROR_CHECK(onboarding_run(&config));
    }

    uint32_t sensor_interval_sec = main_logic_report_interval_sec(config.report_interval_sec);
    uint32_t loops_since_camera = APP_CAMERA_INTERVAL_SEC / sensor_interval_sec;
    uint32_t consecutive_failures = 0;
    static uint32_t seq = 0;

    while (true) {
        sensor_interval_sec = main_logic_report_interval_sec(config.report_interval_sec);

        actuators_tick(profile);

        sensor_snapshot_t snapshot = {0};
        bool camera_due = false;
        bool station_started = false;
        ota_update_t ota;
        ota_update_clear(&ota);

        snapshot.seq = seq++;
        // ageMs = sampling-to-POST latency. Stamp the sample time BEFORE
        // the (slow) ADC+DHT read; the value is filled in right before
        // the POST so sampleTime = receivedAt - ageMs holds server-side.
        int64_t sample_t_us = esp_timer_get_time();

        err = sensors_read_all(profile, &snapshot);
        if (err != ESP_OK) {
            // sensors_read_all returns ESP_OK or ESP_FAIL only.
            consecutive_failures++;
            ESP_LOGE(TAG, "Sensor read failed: %s", esp_err_to_name(err));
        }

        camera_due = main_logic_camera_slot_due(APP_CAMERA_ENABLED != 0 && profile->has_camera,
                                                sensor_interval_sec,
                                                &loops_since_camera);

        if (err == ESP_OK) {
            if (boot_save_failed) {
                if (app_config_save(&config) == ESP_OK) {
                    boot_save_failed = false;
                } else {
                    ESP_LOGE(TAG, "Boot-count re-save failed, snapshotIds may dedup-drop");
                }
            }
            err = network_manager_start_station(&config, WIFI_CONNECT_TIMEOUT_MS);
            if (err != ESP_OK) {
                // Station join returns OK/FAIL/TIMEOUT, all countable:
                // no link means no telemetry either way.
                consecutive_failures++;
                ESP_LOGE(TAG, "WiFi connect failed: %s", esp_err_to_name(err));
            } else {
                station_started = true;

                int64_t now_us = esp_timer_get_time();
                snapshot.age_ms = now_us >= sample_t_us
                    ? (uint32_t) ((now_us - sample_t_us) / 1000LL)
                    : 0;
                err = upload_sensor_snapshot(&config, &snapshot, profile, &ota);
                if (err == ESP_OK) {
                    consecutive_failures = 0;
                } else {
                    if (err != ESP_ERR_INVALID_STATE) {
                        consecutive_failures++;
                    }
                    ESP_LOGE(TAG, "Sensor cycle failed: %s", esp_err_to_name(err));
                }
            }
        }

        if (station_started && camera_due) {
            err = upload_camera_image(profile, &config);
            if (err == ESP_OK) {
                loops_since_camera = 0;
                consecutive_failures = 0;
            } else {
                // Camera-only failure must not force the portal: telemetry
                // is healthy, the still retries at the next due slot.
                if (err != ESP_ERR_INVALID_STATE) {
                    ESP_LOGW(TAG, "Camera frame failed, not counting toward portal: %s",
                             esp_err_to_name(err));
                } else {
                    ESP_LOGE(TAG, "Camera cycle failed: %s", esp_err_to_name(err));
                }
            }
        }

        if (station_started) {
            // OTA runs on the station link before it goes down. A success
            // restarts the device; anything else continues the cycle.
            ota_service_run_if_needed(&ota);
            network_manager_stop();
        }

        if (main_logic_should_reopen_portal(consecutive_failures)) {
            ESP_LOGW(TAG, "Repeated network failures detected, reopening onboarding portal");
            ESP_ERROR_CHECK(onboarding_run(&config));
            consecutive_failures = 0;
            loops_since_camera = 0;
        }

        delay_with_housekeeping(profile, sensor_interval_sec * 1000);
    }
}

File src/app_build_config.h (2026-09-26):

#pragma once

// Developer-managed constants. These are compiled into the firmware and are
// not user-configurable through onboarding or stored in NVS.
#define APP_DEVICE_ID "IAET01"
#define APP_FIRMWARE_VERSION "2.0.0"
#define APP_SENSOR_API_URL "https://avid-mammoth-766.convex.site/api/v1/sensors"
#define APP_CAMERA_API_URL "https://avid-mammoth-766.convex.site/api/v1/camera"
#define APP_API_TOKEN ""
#define APP_MAX_PUMP_DURATION_MS 30000
#define APP_MAX_LIGHT_ON_MS (24ULL * 3600ULL * 1000ULL)
#define APP_OTA_ENABLED 1

#define APP_BOARD_PROFILE 0
#define APP_CAMERA_ENABLED 1

#define APP_SENSOR_SOIL_ENABLED 1
#define APP_SENSOR_LIGHT_ENABLED 1
#define APP_SENSOR_WATER_ENABLED 1
#define APP_SENSOR_TEMPERATURE_ENABLED 1
#define APP_SENSOR_AIR_ENABLED 1

#define APP_SENSOR_INTERVAL_SEC 15
#define APP_CAMERA_INTERVAL_SEC 900

#define APP_ONBOARDING_FAILURE_THRESHOLD 5

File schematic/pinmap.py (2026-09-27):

#!/usr/bin/env python3
"""Extract pin geometry from KiCad symbol S-expr (lib_symbols sections).

Usage: python3 pinmap.py <kicad_sch files...> > pinmap.json
Output: {lib_id: {pin_number: {"x":.., "y":.., "angle":.., "name":..}}}
Coordinates are symbol-local mm; the pin hotspot (wire attach point)
is exactly (x, y). The `angle` gives the pin's exit direction.
"""
import json
import re
import sys


def parse_lib_symbols(text):
    """Yield (lib_id, pin_num, x, y, angle, name) for every pin found."""
    # Find lib_symbols section bounds (first "(lib_symbols" to matching depth).
    start = text.find("(lib_symbols")
    if start < 0:
        return
    lines = text[start:].splitlines()
    depth = 0
    cur_base = None  # canonical "Lib:Name" of the enclosing symbol
    i = 0
    started = False
    while i < len(lines):
        ln = lines[i]
        opens = ln.count("(")
        closes = ln.count(")")
        if not started:
            if "(lib_symbols" in ln:
                started = True
                depth = opens - closes
            i += 1
            continue
        m = re.match(r'\s*\(symbol\s+"([^"]+)"\s*$', ln)
        if m:
            name = m.group(1)
            if name.count(":") == 1 and not re.search(r"_\d+_\d+$", name):
                cur_base = name  # top-level "Lib:Name" header
        if "(pin " in ln and cur_base:
            chunk = "\n".join(lines[i:i + 8])
            at = re.search(r"\(at\s+([-\d.]+)\s+([-\d.]+)(?:\s+([-\d.]+))?", chunk)
            nm = re.search(r'\(name\s+"([^"]*)"', chunk)
            nb = re.search(r'\(number\s+"([^"]*)"', chunk)
            if at and nb:
                ang = float(at.group(3)) if at.group(3) else 0.0
                yield (cur_base, nb.group(1), float(at.group(1)),
                       float(at.group(2)), ang,
                       nm.group(1) if nm else "")
        depth += opens - closes
        if depth <= 0:
            break
        i += 1


def main(files):
    out = {}
    for path in files:
        text = open(path).read()
        for lib_id, num, x, y, ang, name in parse_lib_symbols(text):
            out.setdefault(lib_id, {})[num] = {
                "x": x, "y": y, "angle": ang, "name": name,
            }
    json.dump(out, sys.stdout, indent=1)


if __name__ == "__main__":
    main(sys.argv[1:])

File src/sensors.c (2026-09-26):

#include "sensors.h"

#include <math.h>
#include <stdbool.h>
#include <stdint.h>
#include <stdlib.h>

#include "dht.h"
#include "app_build_config.h"
#include "board_profile.h"
#include "driver/gpio.h"
#include "esp_adc/adc_oneshot.h"
#include "esp_check.h"
#include "esp_log.h"
#include "esp_task_wdt.h"
#include "freertos/FreeRTOS.h"
#include "freertos/task.h"

#define ADC_SAMPLE_COUNT 8

static const char *TAG = "sensors";
static adc_oneshot_unit_handle_t s_adc_handle;
static adc_oneshot_unit_handle_t s_adc1_handle;
static uint32_t s_dht_fail_count;
static uint32_t s_adc_fail_count;

static void mark_measurement_unavailable(sensor_measurement_t *measurement)
{
    measurement->available = false;
    measurement->raw = -1;
    measurement->value = NAN;
}

static int read_adc_average(adc_oneshot_unit_handle_t unit, adc_channel_t channel)
{
    int total = 0;
    int success_count = 0;

    for (int i = 0; i < ADC_SAMPLE_COUNT; ++i) {
        int raw = 0;
        if (adc_oneshot_read(unit, channel, &raw) == ESP_OK) {
            total += raw;
            success_count++;
        }
        esp_task_wdt_reset();
        vTaskDelay(pdMS_TO_TICKS(10));
    }

    if (success_count == 0) {
        return -1;
    }

    return total / success_count;
}

static void read_raw_measurement(sensor_measurement_t *measurement,
                                 bool enabled,
                                 adc_oneshot_unit_handle_t unit,
                                 adc_channel_t channel)
{
    if (!enabled) {
        mark_measurement_unavailable(measurement);
        return;
    }

    measurement->raw = read_adc_average(unit, channel);
    measurement->value = NAN;
    measurement->available = measurement->raw >= 0;
    if (!measurement->available) {
        s_adc_fail_count++;
    }
}

static bool dht_is_enabled(void)
{
    return APP_SENSOR_TEMPERATURE_ENABLED || APP_SENSOR_AIR_ENABLED;
}

static bool read_dht_if_enabled(const board_profile_t *profile, sensor_snapshot_t *snapshot)
{
    if (!dht_is_enabled()) {
        return false;
    }

    gpio_num_t dht_gpio = profile->dht_gpio;
    float humidity = NAN;
    float temperature = NAN;
    bool read_ok = false;

    for (int attempt = 0; attempt < 2; ++attempt) {
        if (dht_read_float_data(DHT_TYPE_AM2301, dht_gpio, &humidity,
                                &temperature) == ESP_OK) {
            read_ok = true;
            break;
        }
        esp_task_wdt_reset();
        vTaskDelay(pdMS_TO_TICKS(2000));
    }

    if (!read_ok) {
        s_dht_fail_count++;
        ESP_LOGW(TAG, "DHT read failed");
        return false;
    }

    snapshot->temperature.available = APP_SENSOR_TEMPERATURE_ENABLED;
    snapshot->temperature.raw = -1;
    snapshot->temperature.value = temperature;
    snapshot->air.available = APP_SENSOR_AIR_ENABLED;
    snapshot->air.raw = -1;
    snapshot->air.value = humidity;
    return true;
}

void sensors_init(const board_profile_t *profile)
{
    const gpio_num_t used[] = {
        profile->water_level_gpio, profile->soil_moisture_gpio,
        profile->light_sensor_gpio, profile->dht_gpio,
        profile->pump_gpio, profile->grow_light_gpio,
    };
    for (size_t i = 0; i < sizeof(used) / sizeof(used[0]); ++i) {
        if (board_profile_gpio_conflicts_with_camera(profile, used[i])) {
            ESP_LOGE(TAG, "GPIO %d conflicts with fixed camera bus, aborting", (int) used[i]);
            abort();
        }
    }

    adc_oneshot_unit_init_cfg_t init_config = {
        .unit_id = profile->analog_unit,
        .ulp_mode = ADC_ULP_MODE_DISABLE,
    };
    ESP_ERROR_CHECK(adc_oneshot_new_unit(&init_config, &s_adc_handle));

    adc_oneshot_unit_init_cfg_t init_config_1 = {
        .unit_id = profile->water_level_unit,
        .ulp_mode = ADC_ULP_MODE_DISABLE,
    };
    ESP_ERROR_CHECK(adc_oneshot_new_unit(&init_config_1, &s_adc1_handle));

    adc_oneshot_chan_cfg_t channel_config = {
        .bitwidth = ADC_BITWIDTH_12,
        .atten = ADC_ATTEN_DB_12,
    };
    ESP_ERROR_CHECK(adc_oneshot_config_channel(s_adc1_handle, profile->water_level_channel, &channel_config));
    ESP_ERROR_CHECK(adc_oneshot_config_channel(s_adc_handle, profile->soil_moisture_channel, &channel_config));
    ESP_ERROR_CHECK(adc_oneshot_config_channel(s_adc_handle, profile->light_sensor_channel, &channel_config));
}

esp_err_t sensors_read_all(const board_profile_t *profile, sensor_snapshot_t *snapshot)
{
    read_raw_measurement(&snapshot->water,
                         APP_SENSOR_WATER_ENABLED,
                         s_adc1_handle,
                         profile->water_level_channel);
    read_raw_measurement(&snapshot->soil,
                         APP_SENSOR_SOIL_ENABLED,
                         s_adc_handle,
                         profile->soil_moisture_channel);
    read_raw_measurement(&snapshot->light,
                         APP_SENSOR_LIGHT_ENABLED,
                         s_adc_handle,
                         profile->light_sensor_channel);
    mark_measurement_unavailable(&snapshot->temperature);
    mark_measurement_unavailable(&snapshot->air);

    read_dht_if_enabled(profile, snapshot);

    if ((APP_SENSOR_WATER_ENABLED && !snapshot->water.available) ||
        (APP_SENSOR_SOIL_ENABLED && !snapshot->soil.available) ||
        (APP_SENSOR_LIGHT_ENABLED && !snapshot->light.available)) {
        ESP_LOGW(TAG, "One or more ADC reads failed");
    }

    ESP_LOGI(TAG, "Water=%d Soil=%d Light=%d Temp=%.1f Air=%.1f",
             snapshot->water.raw,
             snapshot->soil.raw,
             snapshot->light.raw,
             snapshot->temperature.value,
             snapshot->air.value);

    int enabled_count = 0;
    int unavailable_count = 0;

    if (APP_SENSOR_WATER_ENABLED) {
        enabled_count++;
        if (!snapshot->water.available) {
            unavailable_count++;
        }
    }
    if (APP_SENSOR_SOIL_ENABLED) {
        enabled_count++;
        if (!snapshot->soil.available) {
            unavailable_count++;
        }
    }
    if (APP_SENSOR_LIGHT_ENABLED) {
        enabled_count++;
        if (!snapshot->light.available) {
            unavailable_count++;
        }
    }
    if (APP_SENSOR_TEMPERATURE_ENABLED) {
        enabled_count++;
        if (!snapshot->temperature.available) {
            unavailable_count++;
        }
    }
    if (APP_SENSOR_AIR_ENABLED) {
        enabled_count++;
        if (!snapshot->air.available) {
            unavailable_count++;
        }
    }

    if (enabled_count > 0 && unavailable_count == enabled_count) {
        return ESP_FAIL;
    }

    return ESP_OK;
}

void sensors_get_fail_counts(uint32_t *dht_fails, uint32_t *adc_fails)
{
    if (dht_fails != NULL) {
        *dht_fails = s_dht_fail_count;
    }
    if (adc_fails != NULL) {
        *adc_fails = s_adc_fail_count;
    }
}

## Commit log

2026-05-29 Initial commit: Production-ready ESP32-CAM firmware
    Complete IoT plant monitoring system for ESP32-CAM:
    - Multi-sensor monitoring (soil, light, water, temperature, humidity)
    - Camera integration with OV2640
    - WiFi onboarding portal
    - Cloud API integration
    - Automatic failure recovery
    - Low power consumption (~500mA)
    - Fast boot time (2-3 seconds)
    Documentation:
    - User-friendly README following makeareadme.com
    - GPLv3 license
    - Comprehensive docs (HARDWARE, TROUBLESHOOTING, DEVELOPMENT, CONFIGURATION, API)
    - Complete hardware guide with BOM and wiring diagrams
    - PlatformIO build system
    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
    [partitions.csv]
2026-09-05 pin patched component builds (DHT22, esp32-camera, esp-idf-lib slimmed)
    Nested component repos carry local patches committed in-place; parent pins
    the patched commits. Note: fresh clones get upstream HEAD, not these patches.
2026-09-26 All managed deps, text-only wiring, growmate-pods naming
    - Drop hardware/ CAD + figures: wiring is text-only in docs/04-wiring.md
    - All deps via component manager (src/idf_component.yml): esp-idf-lib/dht,
    espressif/esp32-camera; delete vendored components/ and esp-idf-lib
    - sensors.c: stateless DHT reads, drop init/deinit ISR dance
    - Rename project esp32_cam_flash_blink -> growmate_pods, env -> growmate-pods
    - platformio.ini slimmed; manual flash moved to tools/flash.sh
    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
2026-09-26 Water probe GPIO12 -> GPIO33 (ADC1), drop switched supply
    MTDI-safe by construction: GPIO12 unconnected, probe on strapping-free
    GPIO33/ADC1 (also WiFi-safe). sensors.c runs ADC1+ADC2 units. R7 gone,
    R9 now defines EMPTY on the water net. Docs updated throughout.
2026-09-26 Docs robustness pass: C4 in BOM/nets, endpoint+auth precision, flash power rule
2026-09-26 Fix all gaps: pump safety timer, raw-only v1 contract, acks, health, docs
    [actuators.c, api_client.c, app_build_config.h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]
2026-09-26 OTA, claim flow, per-device AP password, light failsafe (no invented hardware)
    [partitions.csv]
2026-09-26 Full reread hardening: ageMs latency, resetReason string, NVS v5 migration, OTA guards, partition custom, fb_location, doc alignment
    [api_client.c, board_profile.c, camera_service.c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]
2026-09-26 Think-hard pass: chunked 429 wait with WDT feed, honest non-const config signature, drop dead INVALID_STATE checks, single ensure_terminated, NVS v1 doc fix
    [api_client.c, main.c]
2026-09-26 Reverse-audit fixes: break on fatal/429-wait, strict semver, SSID bounds, claim rollback, doc wording
    [api_client.c, board_profile.c, main.c]
2026-09-26 Wiring review: 10k gate PDs, BOD on, fuses, TP4056 honesty, probe care
2026-09-27 Audit fixes all: camera isolation, boot-save retry, AP password silence, 10k PD comment, fuse nodes, seq/ageMs contract notes, host contract tests
    [actuators.c, main.c]
2026-09-27 Production schematics pods rev A: SKiDL truth + placed hierarchical sheets + BOM + PDF + ERC log
    [bom.csv, pods.kicad_sch, pods_s_boost1.kicad_sch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]
2026-09-27 Split PUMP_5V/LED_5V rails per SKiDL truth; flat draft guard
    Pump/LED sheets used power:+5V symbols, joining the separately-fused
    F2/F3 branches. Now PUMP_5V/LED_5V global labels; netlists match
    pods.net pin-for-pin (full compare zero). pods.py flatness=1.0 so the
    SKiDL draft can never clobber placed pods_s_* sheets. Docs net names.
    [pods_s_boost1.kicad_sch, pods_s_branches1.kicad_sch, pods_s_charge1.kicad_sch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]
2026-09-27 Regen SKiDL artifacts with flat draft (date/tag churn only, BOM stable at 41)
    [pods.kicad_sch]
2026-09-28 Audit fixes: doc footprint strings, GPIO33 LED note, D1 1N5822
    04-wiring footprint column now matches pods.py/BOM (U2/SW1/M1/D2).
    GPIO33 red-LED load disclosed like GPIO4. Pump flyback 1N5819 -> 1N5822
    (DO-41, 3A class for 2A stall turn-off). ERC gate holds, full netlist
    compare zero, PDF/final refreshed.
    [bom.csv, pods.kicad_sch, pods_s_boost1.kicad_sch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]
2026-09-28 Owner decisions: OUT+/- rewire (CELL_NEG), XL6009 boost, server XOR
    [bom.csv, pods.kicad_sch, pods_s_boost1.kicad_sch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]
2026-09-28 Track inspection images; ignore only scratch (insp, per-sheet rpts)
2026-09-28 Organize schematic/: sheets/ mfg/ final/, drop sklib
    [bom.csv, pods.kicad_sch, pods_s_boost1.kicad_sch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]
2026-09-28 tools/: device workflow, tests, schematic gate/plot/compare
